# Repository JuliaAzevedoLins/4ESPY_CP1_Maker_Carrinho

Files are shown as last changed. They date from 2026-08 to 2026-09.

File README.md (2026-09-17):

# Carrinho Robótico WALL-E — 4ESPY | CP1

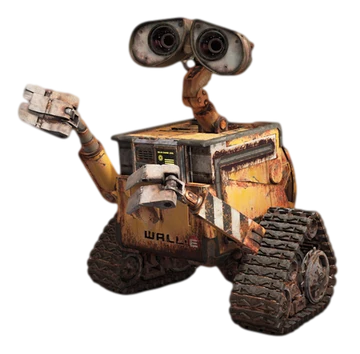
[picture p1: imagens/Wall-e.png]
WALL-E


Carrinho robótico físico e funcional, construído sobre um corpo impresso em 3D inspirado no personagem WALL-E (Pixar). O robô se movimenta por **duas rodas** acionadas por motores DC independentes, é pilotado à distância por um **controle PS5 DualSense** via Bluetooth e detecta obstáculos com um **sensor ultrassônico HC-SR04**, que bloqueia automaticamente o avanço diante de uma colisão iminente.

- **Turma:** 4ESPY
- **Avaliação:** CP1
- **Alunos:**
  - Julia Azevedo Lins — RM 98690
  - Luis Gustavo Barreto Garrido — RM 99210
  - Victor Hugo Aranda Forte — RM 99667
  - Felipe Cortez — RM 99750
  - Guilherme Akio — RM 98582

## Objetivo

Desenvolver um carrinho robótico funcional que integre projeto mecânico, fabricação digital, eletrônica e programação — capaz de se deslocar para frente e para trás, fazer curvas, receber comandos sem fio e reagir a obstáculos detectados por sensor.

## Principais funcionalidades

| Funcionalidade | Como funciona |
|---|---|
| **Locomoção diferencial** | Dois motores DC independentes acionam as rodas laterais. Frente, ré, curvas e giro sobre o próprio eixo |
| **Controle sem fio** | Controle PS5 DualSense por Bluetooth clássico (biblioteca Bluepad32). Stick esquerdo: avanço/ré. Stick direito: giro |
| **Velocidade proporcional** | PWM de 1 kHz com rampa de aceleração suave. Os gatilhos **R2/L2** ajustam a velocidade máxima em tempo real |
| **Freio de segurança** | O HC-SR04 bloqueia o avanço a menos de 20 cm de um obstáculo — mantendo ré e giro liberados, para o robô nunca ficar preso |
| **Calibração pelo celular** | O ESP32 serve uma página web com sliders que compensam a diferença de rotação entre os motores. Valores salvos na memória interna |
| **Atualização OTA** | Depois da primeira gravação por cabo, o firmware é atualizado pela rede Wi-Fi — sem abrir o corpo impresso |

## O carrinho finalizado

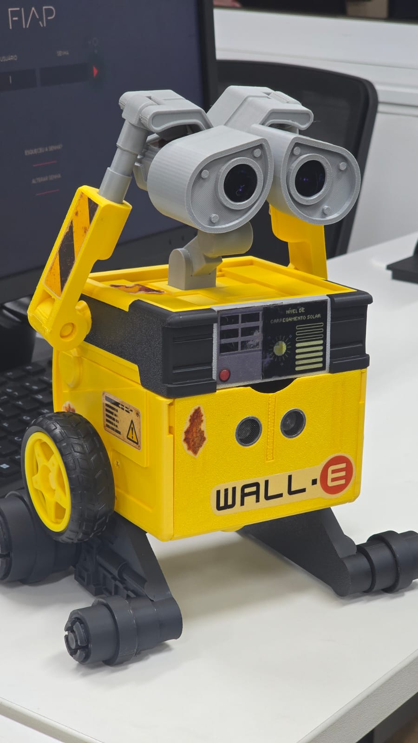
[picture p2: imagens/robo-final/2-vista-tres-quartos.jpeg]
Carrinho robótico WALL-E finalizado


| Vista frontal | Vista lateral | Eletrônica interna |
|---|---|---|
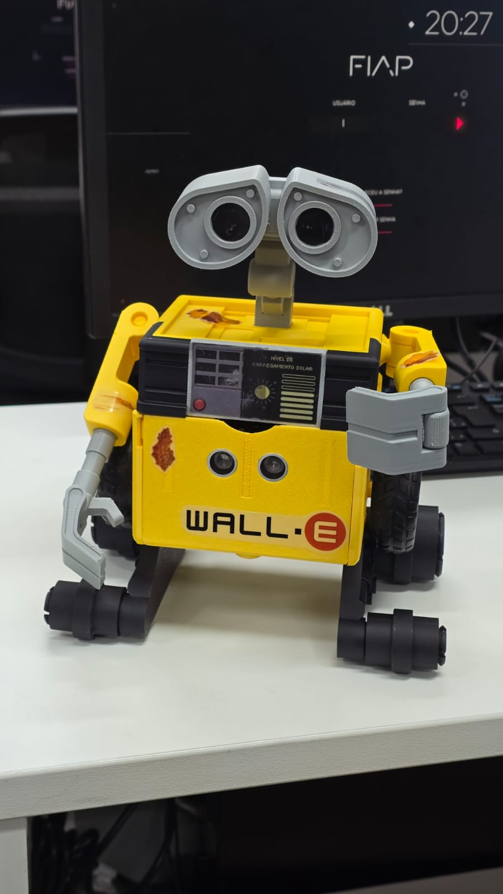
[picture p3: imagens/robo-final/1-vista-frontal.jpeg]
Vista frontal
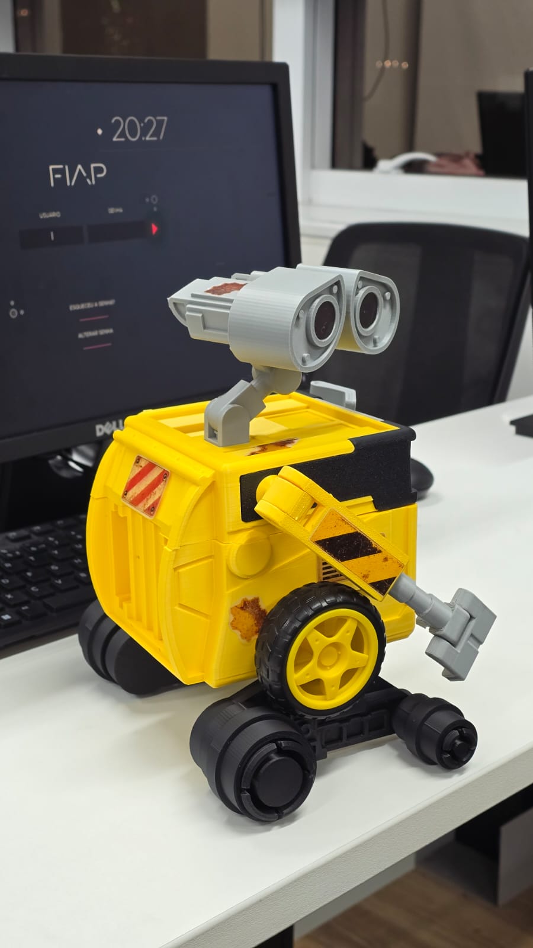
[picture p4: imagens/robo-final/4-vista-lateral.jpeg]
Vista lateral
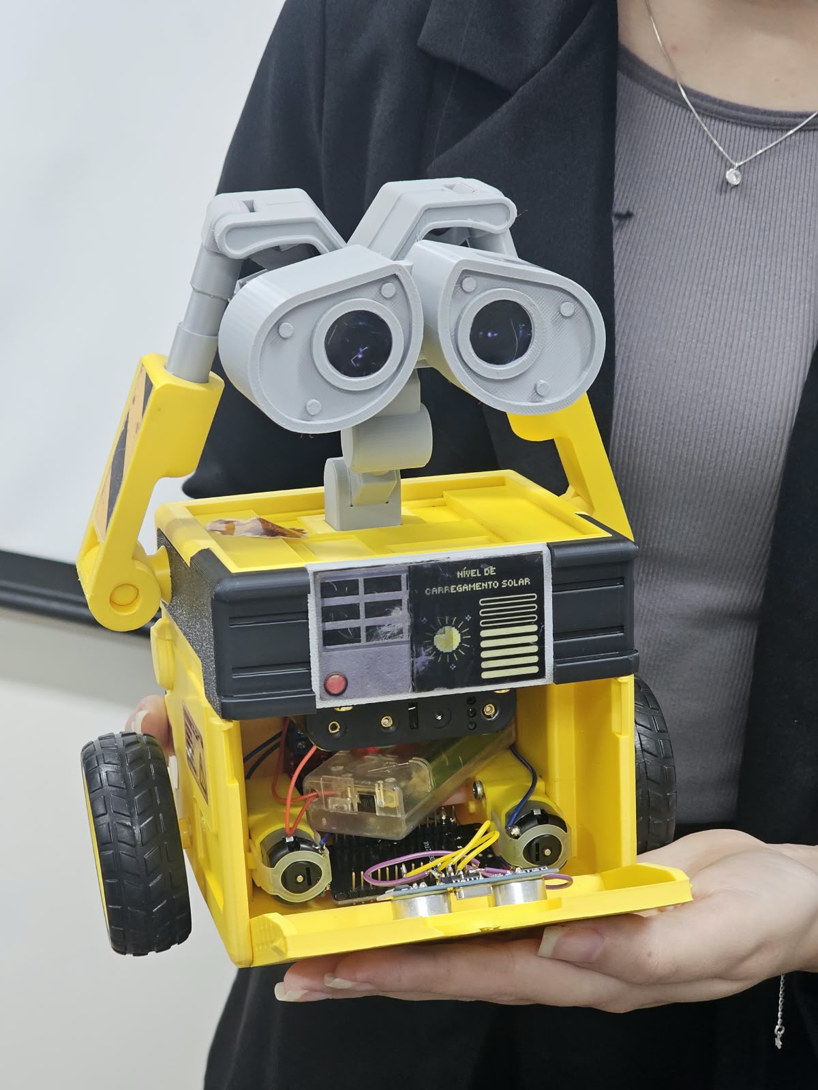
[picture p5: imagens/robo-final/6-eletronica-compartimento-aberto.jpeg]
Compartimento aberto
|  |  |  |

O sensor HC-SR04 fica embutido na face frontal e a tampa dianteira abre para baixo, dando acesso aos motores, à ponte H, ao ESP32 e às pilhas sem desmontar nada. O acabamento inclui pintura de desgaste, faixa preta no topo e adesivos ("WALL·E", painel de carregamento solar e etiquetas de advertência).

Mais fotos em [`imagens/robo-final/`](imagens/robo-final).

🎥 **Vídeos do funcionamento:** [1](<vídeo/funcionamento-1.mp4>) · [2](<vídeo/funcionamento-2.mp4>) · [3](<vídeo/funcionamento-3.mp4>) · [4](<vídeo/funcionamento-4.mp4>) — o robô em operação, comandado pelo controle PS5. A demonstração do sensor de aproximação está em [`vídeo/Motor + Sensor de Aproximação.mp4`](<vídeo/Motor + Sensor de Aproximação.mp4>).

## Especificações

| Item | Valor |
|---|---|
| Microcontrolador | ESP32 Dev Module (Bluetooth clássico) |
| Driver de motores | Ponte H dupla, 4 entradas em PWM |
| Motores | 2 × DC TT com caixa de redução |
| Tração | 2WD diferencial, 2 rodas laterais + apoio frontal impresso |
| Sensor | HC-SR04 frontal, detecção a 20 cm |
| Controle | PS5 DualSense (Bluepad32) |
| Alimentação | 6 × pilhas AA com chave liga/desliga |
| Estrutura | Corpo impresso em PLA — 204,4 × 126,0 × 77,7 mm |

## Como usar

1. Ligue a chave do suporte de pilhas.
2. Coloque o DualSense em pareamento: segure **PS + Create** até o LED piscar rápido.
3. Pilote: **stick esquerdo** anda e dá ré, **stick direito** gira, **R2/L2** ajustam a velocidade.
4. A menos de 20 cm de um obstáculo o avanço trava sozinho — use ré ou giro para sair.

Instruções completas (calibração, gravação do firmware e solução de problemas) na [seção 27 da documentação](Documentacao.md).

## Organização do repositório

```
├── README.md                     # este arquivo
├── Documentacao.md               # documentação técnica completa (28 seções)
│
├── Códigos/                      # firmware
│   ├── PS5_ESP32_Bluepad32.ino        # ⭐ firmware oficial do robô (ESP32)
│   ├── secrets.h.example              # modelo das credenciais de Wi-Fi
│   ├── README.md                      # setup, compilação e uso
│   └── testes-aula16/                 # códigos históricos dos testes de bancada
│
├── Modelo 3d/                    # projeto mecânico
│   ├── Wall-E_Articulated(3).3mf      # projeto do slicer (16 chapas)
│   ├── stl/                           # STL das peças modeladas pela equipe
│   ├── renders/                       # renders das 16 chapas de impressão
│   └── README.md                      # modelagem, adaptações e parâmetros
│
├── Organização/                  # planejamento e gestão
│   ├── MVP.html                       # produto mínimo viável e critérios de aceite
│   ├── MoSCoW.html                    # priorização Must/Should/Could/Won't
│   ├── Backlog.html                   # tarefas, responsáveis, prazos e critérios
│   ├── Dependências.html              # precedências e caminho crítico
│   ├── Kanban.html                    # situação das atividades
│   ├── Planilha-de-custos.xlsx        # custos (Excel)
│   ├── Resumo-Planilha-de-custos.html # resumo visual dos custos
│   └── README.md                      # índice dos entregáveis e equipe
│
├── croqui/                       # croqui da concepção inicial
├── imagens/                      # fotos do projeto
│   └── robo-final/                    # fotos do robô finalizado
└── vídeo/                        # vídeos dos testes e da demonstração final
```

## Documentação

A [documentação técnica completa](Documentacao.md) é **cumulativa** e registra todo o processo:

| Seções | Conteúdo |
|---|---|
| 1 – 19 | Concepção, requisitos, especificações, chassi, carenagem e croqui |
| 20 – 21 | Montagem e testes de bancada (Arduino Uno) — registro histórico |
| 22 | Planejamento e gestão |
| **23** | **Projeto mecânico e fabricação** — adaptações, peças próprias, impressão |
| **24** | **Hardware, eletrônica e firmware** — pinagem, alimentação, funcionamento do código |
| **25** | **Testes, problemas e correções** — 10 testes e 12 problemas resolvidos |
| **26** | **Evolução e decisões de projeto** |
| **27** | **Instruções de uso** |
| **28** | **Evidências finais** |

Os artefatos de planejamento (MVP, MoSCoW, backlog, dependências, kanban e custos) estão na pasta [`Organização/`](<Organização/README.md>).

## Status do projeto

- [x] Ficha de requisitos, requisitos funcionais e físicos, especificações e lista de componentes
- [x] Arquitetura do sistema e distribuição dos componentes
- [x] Croqui do chassi (concepção)
- [x] Diagrama de blocos e de alimentação, validados em bancada
- [x] Testes de bancada: motores, sensor de aproximação e controle sem fio
- [x] Modelagem 3D: adaptação do corpo, extensor de eixo, roda boba e travessa interna
- [x] Impressão 3D de todas as peças do corpo, dos braços, da cabeça e dos conjuntos laterais
- [x] Migração para ESP32 com controle PS5, calibração web e OTA
- [x] Integração final: mecânica + eletrônica + firmware
- [x] Acabamento: pintura de desgaste, faixa preta e adesivos
- [x] Fotos do robô finalizado e vídeos da demonstração

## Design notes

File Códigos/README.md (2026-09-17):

# Firmware — Carrinho Robótico WALL-E

Carrinho de tração diferencial controlado por um **controle PS5 DualSense** via Bluetooth, usando um **ESP32**.

| Arquivo | O que é |
|---|---|
| [`PS5_ESP32_Bluepad32.ino`](PS5_ESP32_Bluepad32.ino) | ⭐ **Firmware oficial** — o que roda no robô entregue |
| [`secrets.h.example`](secrets.h.example) | Modelo das credenciais de Wi-Fi (copiar para `secrets.h`) |
| [`testes-aula16/`](testes-aula16) | Códigos históricos dos testes de bancada em Arduino Uno |

## Recursos

- Conexão com o controle DualSense via [Bluepad32](https://github.com/ricardoquesada/bluepad32) (mais estável que as libs baseadas em spoof de MAC).
- Controle diferencial: stick esquerdo (frente/ré) + stick direito (giro).
- Rampa de aceleração suave e zona morta nos sticks.
- R2/L2 ajustam a velocidade máxima em tempo real.
- **Freio de segurança por sensor**: o HC-SR04 bloqueia o avanço a menos de 20 cm de um obstáculo, mantendo ré e giro liberados.
- **OTA**: depois da primeira gravação por cabo, novas versões do firmware podem ser enviadas pela rede Wi-Fi (`Tools > Port` no Arduino IDE mostra o carrinho como porta de rede).
- **Calibração pelo celular**: o ESP32 sobe uma página web simples (`http://<ip-do-esp32>/`) com sliders para compensar motores desbalanceados, salvos na memória interna (NVS).

## Hardware

- ESP32 Dev Module (precisa de Bluetooth clássico — não funciona em chips só-BLE como S2/S3/C3/C6)
- Driver de motor duplo (ponte H) — 4 pinos de controle: `IN1`, `IN2` (motor A), `IN3`, `IN4` (motor B)
- 2 motores DC TT com caixa de redução
- Sensor ultrassônico HC-SR04
- Controle PS5 DualSense
- 6 × pilhas AA

### Pinagem

| Sinal | GPIO | Canal LEDC |
|---|---|---|
| IN1 — motor A | 26 | 0 |
| IN2 — motor A | 27 | 1 |
| IN3 — motor B | 32 | 2 |
| IN4 — motor B | 33 | 3 |
| TRIG — HC-SR04 | 4 | — |
| ECHO — HC-SR04 | 18 | — |

> ⚠️ **Alimente o HC-SR04 em 3,3 V**, não em 5 V. Em 5 V o pino ECHO devolve 5 V e danifica o GPIO do ESP32, que tolera apenas 3,3 V. Em 3,3 V o sensor dispensa divisor resistivo.

> O motor B tem a polaridade invertida **em software** (`aplicaMotorB()`), porque os dois motores ficam montados espelhados no corpo. Trocar os fios do motor B na ponte H quebra esse pareamento.

## Configuração antes de compilar

1. Instale o pacote de placas do Bluepad32 (ver [instruções do projeto](https://github.com/ricardoquesada/bluepad32)).
2. No Arduino IDE, selecione a placa `ESP32 Bluepad32 Arduino / ESP32 + Bluepad32 Arduino > ESP32 Dev Module`.
3. Em `Tools > Partition Scheme`, escolha uma opção **com OTA** (não use nada com "No OTA" no nome).
4. Copie `secrets.h.example` para `secrets.h` e preencha com o nome e senha da sua rede wifi:
   ```cpp
   const char* WIFI_SSID = "sua-rede";
   const char* WIFI_PASS = "sua-senha";
   ```
   `secrets.h` está no `.gitignore` e nunca deve ser commitado.
5. Grave por cabo USB a primeira vez.

## Uso

- Ao ligar, o ESP32 conecta no wifi e imprime o IP no Serial Monitor (115200 baud).
- Coloque o DualSense em modo pareamento (segure PS + Create até o LED piscar rápido).
- Depois da primeira gravação, novas atualizações podem ser feitas por OTA (mesma rede wifi, sem cabo).
- Para calibrar os motores, acesse `http://<ip-do-esp32>/` pelo celular (mesma rede) e ajuste os sliders enquanto anda com o carrinho pra frente.

### Se o controle não conectar

Descomente `BP32.forgetBluetoothKeys();` no `setup()`, grave, ligue uma vez e comente de novo. Isso apaga pareamentos antigos guardados no ESP32.

## Explicação do funcionamento

O detalhamento da lógica do firmware — mistura diferencial, zona morta, rampa de aceleração, freio de segurança, calibração web e OTA — está na **seção 24** da [documentação técnica](../Documentacao.md).

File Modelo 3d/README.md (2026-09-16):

# Modelagem 3D e Fabricação — Carrinho Robótico WALL-E

Esta pasta reúne o projeto mecânico do robô: o arquivo de projeto do slicer, os STL das peças desenvolvidas pela equipe e os renders das chapas de impressão.

## Conteúdo

| Arquivo / pasta | O que é |
|---|---|
| `Wall-E_Articulated(3).3mf` | Projeto completo no Bambu Studio — 16 chapas, todas as peças posicionadas, cortes e perfis de impressão |
| `stl/` | STL das peças **desenvolvidas/adaptadas pela equipe** |
| `renders/` | Renders das 16 chapas de impressão, extraídos do próprio projeto |

## Modelo base

O corpo, a cabeça, os braços e os conjuntos laterais partem do modelo **"WALL-E Robot - Articulated"**, do designer **RoboDIYer** (MakerWorld, `DesignModelId US945b2b739cf63c`, Standard Digital File License). O modelo original é uma figura articulada decorativa, com esteiras funcionais em TPU, montagem por encaixe e sem qualquer previsão de eletrônica embarcada.

A equipe partiu dele e o converteu em um robô motorizado. As adaptações estão descritas abaixo.

## Adaptações feitas pela equipe

O modelo original é uma figura de brinquedo: as esteiras giram livres, empurradas com a mão. Transformá-lo em um carrinho motorizado exigiu quatro intervenções no projeto mecânico.

> **Tração na versão montada.** O conjunto de esteiras do modelo original não foi usado como elemento de tração. Na montagem final, cada motor aciona uma **roda de borracha** fixada ao seu eixo pelo extensor impresso, e os conjuntos laterais impressos (track frames com roletes) permanecem no robô como **apoio no piso e elemento visual** das esteiras do personagem. O projeto do slicer mantém as peças `Track x2` e o perfil de TPU do modelo original — elas não fazem parte do robô entregue.

| Peça | Dimensões | Por que existe |
|---|---|---|
| `corpo-wall-e-furado.stl` | 204,4 × 126,0 × 77,7 mm | Corpo do WALL-E perfurado por operação booleana. Os furos abrem passagem para os eixos dos motores DC, para a fiação e para o sensor HC-SR04 na face frontal. O modelo original é maciço nessas regiões. |
| `extensor-de-eixo.stl` (×2) | 7,6 × 24,0 × 6,4 mm | **Peça-chave do projeto.** Acopla o eixo do motor DC TT à roda motriz. O motor fica dentro do corpo e a roda, fora da lateral — o extensor vence essa distância e transmite o torque. Sem ele, não há como motorizar o modelo original. |
| `roda-boba-caster.stl` | 86,0 × 36,0 × 15,0 mm | Suporte de roda boba. Como a tração passou a ser motorizada e concentrada nas duas rodas laterais, o conjunto precisou de pontos de apoio adicionais para não cabecear. Atende ao requisito RFIS05. |
| `travessa-interna.stl` | 98,0 × 25,0 × 14,0 mm | Travessa interna que sustenta e alinha os motores dentro do corpo, mantendo os dois eixos coaxiais. |

### Corte do corpo para impressão

O corpo montado tem 204 × 126 × 78 mm e não cabia em uma única chapa com orientação adequada. Ele foi **seccionado dentro do Bambu Studio** em três partes (`Body_B_B`, `Body_B_B_A`, `Body_B_B_B_B`), reunidas por **7 pinos de encaixe** (`Conector-1` a `Conector-7`, duplicados nas duas interfaces de corte).

O corte trouxe um ganho que não estava previsto: o corpo passou a **abrir**, dando acesso à eletrônica interna (ESP32, ponte H e pilhas) sem desmontar rodas, braços ou cabeça. Isso atende diretamente ao requisito RFIS06 — a carenagem não pode impedir o acesso aos componentes para manutenção.

Uma primitiva cilíndrica (`Genérico-Cilindro`) foi usada como ferramenta de subtração booleana para abrir as passagens de eixo.

## Chassi e carenagem são a mesma peça

Na concepção inicial (seção 14 da [documentação técnica](../Documentacao.md)) o projeto previa duas peças distintas: um chassi plano de 220 × 140 × 35 mm e uma carenagem estética montada por cima.

Na versão final essa separação deixou de existir. **O corpo impresso do WALL-E é, ao mesmo tempo, a estrutura que sustenta os componentes e a carenagem estética.** Os motores, o ESP32, a ponte H e as pilhas ficam alojados dentro dele; as rodas motrizes saem pelas laterais, acopladas aos eixos dos motores, e os conjuntos laterais impressos apoiam o robô no piso.

A mudança eliminou uma peça, reduziu o peso e melhorou o resultado visual — o robô é o personagem, e não um chassi com uma casca por cima.

## Parâmetros de impressão

| Parâmetro | Valor |
|---|---|
| Impressora | Bambu Lab A1, bico 0,4 mm |
| Perfil | 0.20 mm Standard @BBL A1 |
| Altura de camada | 0,2 mm |
| Paredes | 2 |
| Preenchimento | 15% |
| Suporte | Árvore (automático) |
| Brim | Automático |
| Chapas | 16 |
| Filamentos | 5 × PLA (amarelo, preto, prata, vermelho, cinza) + 1 × TPU 95A (peças do modelo original, não utilizadas) |

Peças que devem ser impressas juntas, como conjunto *print-in-place* (não separar nas chapas): corpo + tampa frontal; braço + junta de ombro; antebraço + garra.

## Acabamento

Depois de impressas, as peças receberam um trabalho de acabamento que não vem do modelo original:

- **Pintura de desgaste (weathering)** simulando ferrugem e sujeira no corpo, nos braços e na cabeça, reproduzindo o aspecto envelhecido do personagem no filme;
- **Faixa preta texturizada** aplicada no topo e nas laterais superiores do corpo;
- **Adesivos impressos**: logotipo "WALL·E" na tampa frontal, painel "NÍVEL DE CARREGAMENTO SOLAR" na face superior, etiqueta de advertência na lateral e faixas de perigo no braço;
- **Impressão multicolor** separando corpo (amarelo), cabeça e braços (cinza), conjuntos laterais e painel (preto) e detalhes (vermelho).

As fotos do resultado estão em [`imagens/robo-final/`](../imagens/robo-final).

## Versões do modelo

| Versão | Registro |
|---|---|
| v1 | Modelo base importado do MakerWorld, sem alterações |
| v2 | `Wall-E_Articulated(2).3mf` — corte do corpo e primeiros furos |
| v3 | `Wall-E_Articulated(3).3mf` — **versão atual**: furação final, extensor de eixo, roda boba, travessa interna e reorganização das 16 chapas |

O encadeamento das versões está registrado dentro do próprio projeto: cada peça do arquivo atual carrega o metadado `source_file` apontando para `Wall-E_Articulated(2).3mf`.

## Renders das chapas

Os 16 renders em `renders/` mostram o arranjo de cada chapa de impressão exatamente como foi enviado à impressora.

| | | | |
|---|---|---|---|
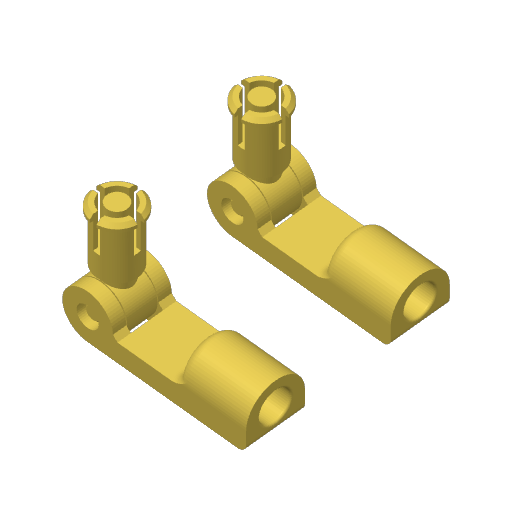
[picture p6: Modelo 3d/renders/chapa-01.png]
Chapa 1
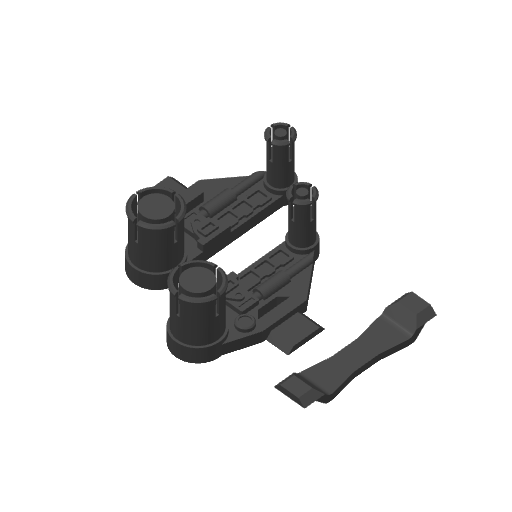
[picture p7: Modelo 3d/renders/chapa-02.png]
Chapa 2
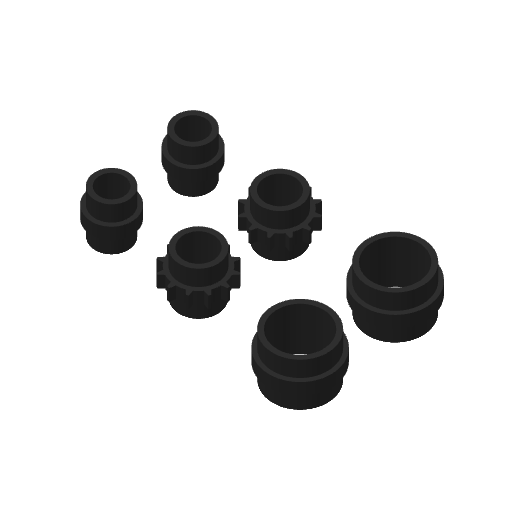
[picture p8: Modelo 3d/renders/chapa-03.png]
Chapa 3
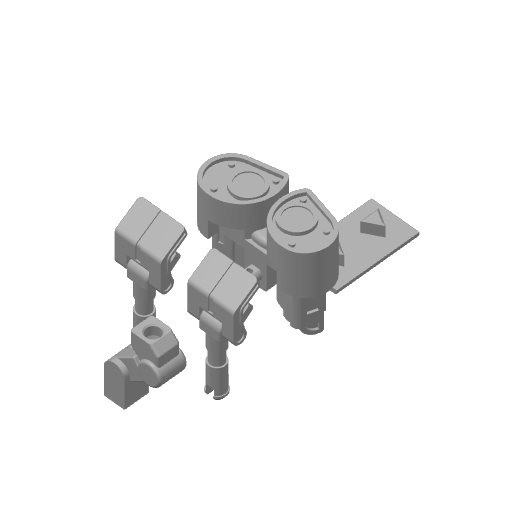
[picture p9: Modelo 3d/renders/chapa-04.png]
Chapa 4
|  |  |  |  |
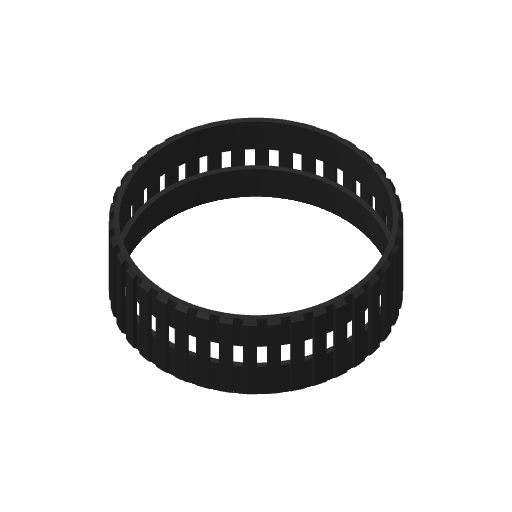
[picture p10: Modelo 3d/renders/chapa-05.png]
Chapa 5
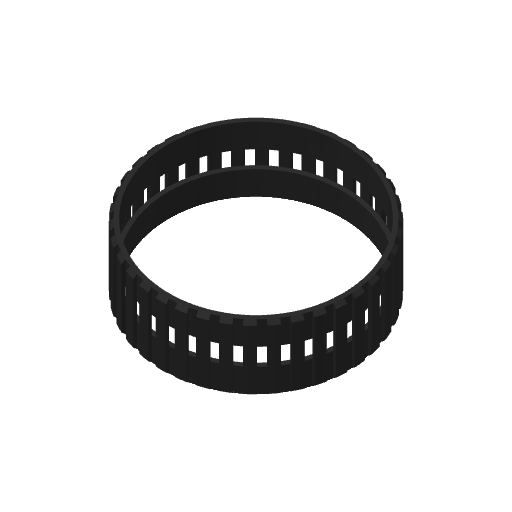
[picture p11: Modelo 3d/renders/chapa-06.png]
Chapa 6
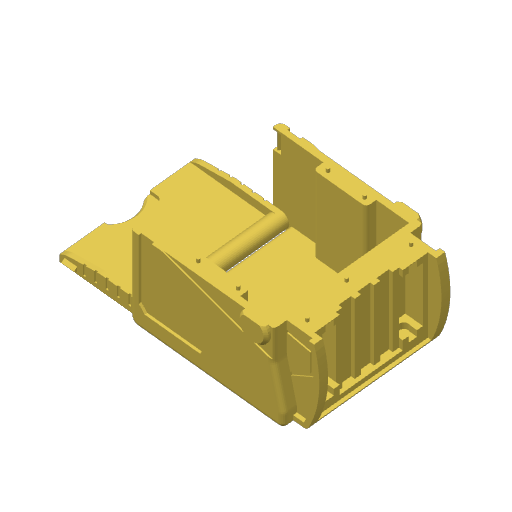
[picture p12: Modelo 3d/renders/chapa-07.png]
Chapa 7
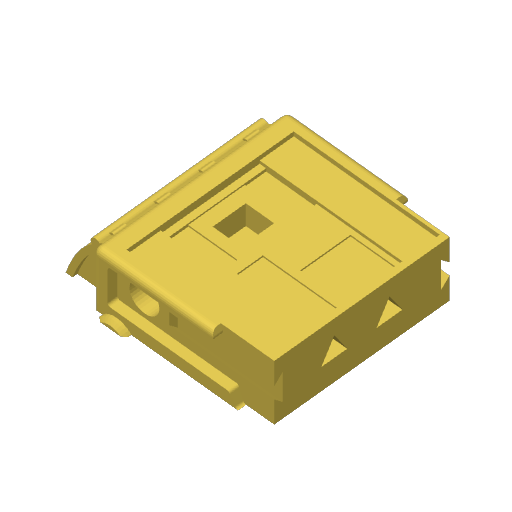
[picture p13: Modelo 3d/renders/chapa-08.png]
Chapa 8
|  |  |  |  |
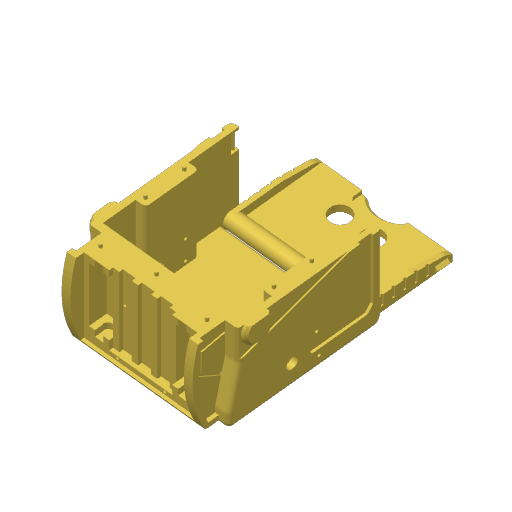
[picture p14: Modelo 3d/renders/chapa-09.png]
Chapa 9
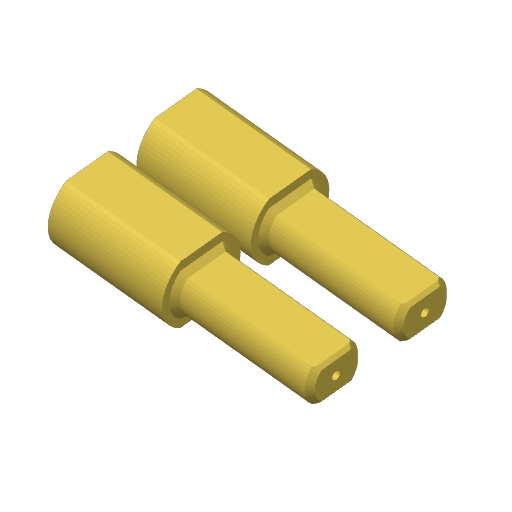
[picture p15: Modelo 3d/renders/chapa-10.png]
Chapa 10
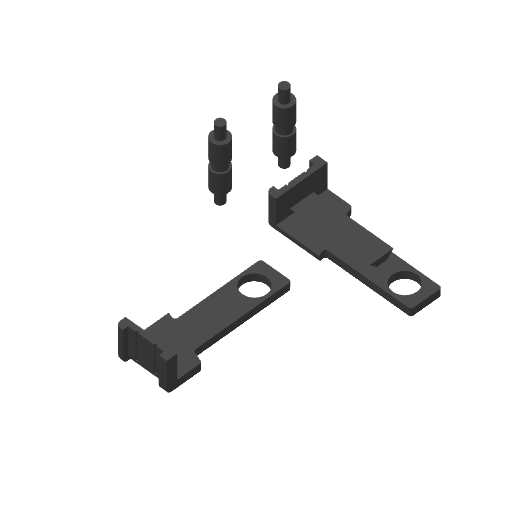
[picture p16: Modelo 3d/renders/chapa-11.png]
Chapa 11
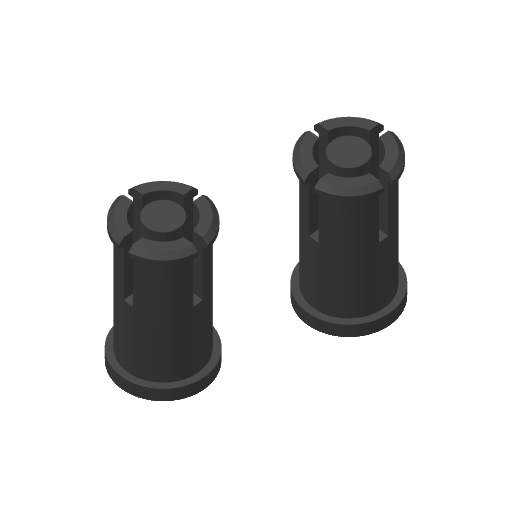
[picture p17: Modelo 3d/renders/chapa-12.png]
Chapa 12
|  |  |  |  |
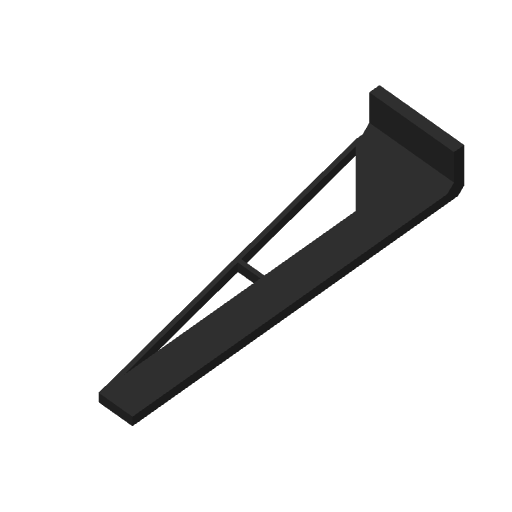
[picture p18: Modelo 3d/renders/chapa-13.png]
Chapa 13
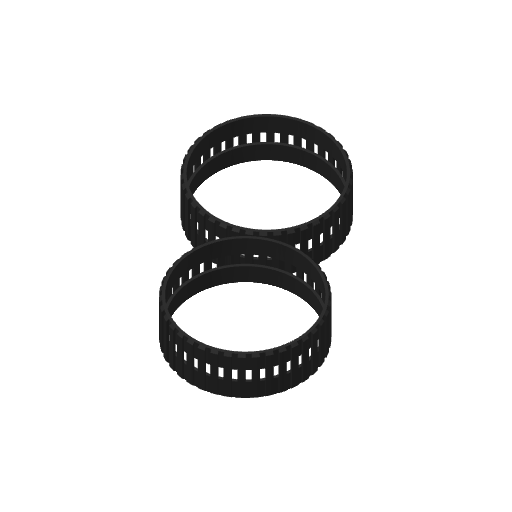
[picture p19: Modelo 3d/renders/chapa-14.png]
Chapa 14
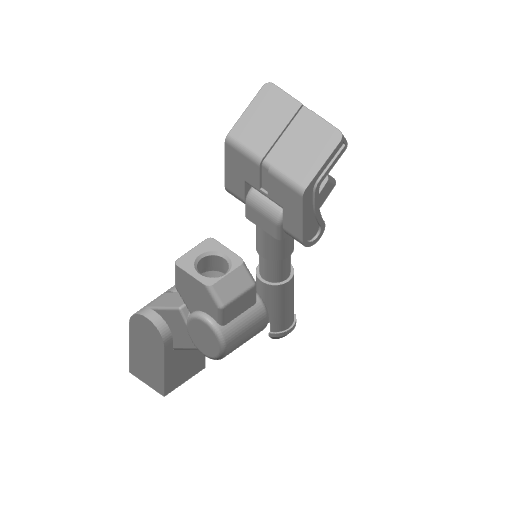
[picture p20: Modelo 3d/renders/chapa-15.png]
Chapa 15
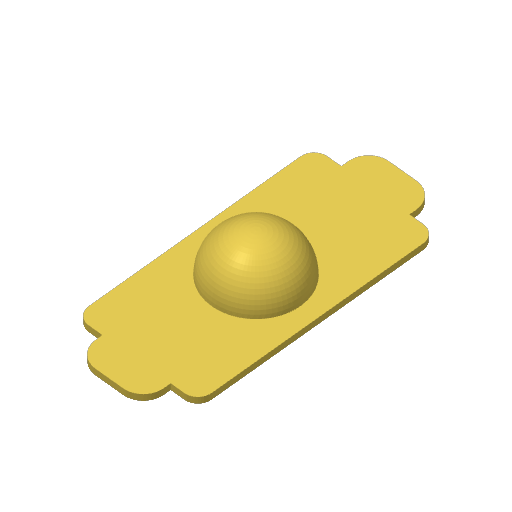
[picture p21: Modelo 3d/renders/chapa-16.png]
Chapa 16
|  |  |  |  |

## Como reproduzir

1. Abra `Wall-E_Articulated(3).3mf` no Bambu Studio (2.07 ou superior).
2. Confirme o perfil `0.20mm Standard @BBL A1` e a impressora Bambu Lab A1 com bico 0,4 mm.
3. Fatie e imprima chapa por chapa. As chapas das peças `Track x2`, em TPU, podem ser puladas: elas não fazem parte do robô entregue.
4. Aplique o acabamento descrito acima.
5. Para reimprimir apenas as peças da equipe, use os STL em `stl/` — eles já saem nas dimensões finais, em milímetros.

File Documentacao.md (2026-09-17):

# Carrinho Robótico WALL-E

WALL-E

## Identificação Acadêmica

- **Turma:** 4ESPY
- **Avaliação:** CP1
- **Alunos:**
  - Julia Azevedo Lins — RM 98690
  - Luis Gustavo Barreto Garrido — RM 99210
  - Victor Hugo Aranda Forte — RM 99667
  - Felipe Cortez — RM 99750
  - Guilherme Akio — RM 98582

---

## 1. Título do Projeto

**Carrinho Robótico WALL-E** — Projeto de carrinho robótico físico e funcional, com carenagem estética inspirada no personagem WALL-E (filme *WALL-E*, Pixar).

---

## 2. Descrição do Projeto

O projeto **Carrinho Robótico WALL-E** consiste em um carrinho robótico físico e funcional, desenvolvido na disciplina de Project-based Maker Lab. O robô é construído sobre um corpo impresso em 3D inspirado no personagem WALL-E (Pixar), movimenta-se por meio de duas rodas acionadas por motores DC independentes, é comandado à distância por um controle **PS5 DualSense** via Bluetooth e detecta obstáculos com um sensor ultrassônico **HC-SR04**, que bloqueia automaticamente o avanço diante de uma colisão iminente.

O projeto atravessou três etapas: concepção e ficha de requisitos (seções 1 a 19), montagem e testes de bancada (seções 20 e 21) e integração da versão final entregue (seções 23 a 28).

---

### Como ler este documento

Este documento é **cumulativo**: ele preserva o registro de cada etapa, inclusive das decisões que foram depois revistas, porque a evolução do projeto faz parte da entrega.

| Seções | O que contêm | Status |
|---|---|---|
| 1 a 19 | Concepção inicial, ficha de requisitos, croqui | Atualizadas para a versão final; onde a concepção foi superada, o texto indica o que mudou e por quê |
| 20 e 21 | Montagem de bancada e testes com Arduino Uno | **Registro histórico** — não descrevem o robô entregue |
| 23 a 28 | Versão final: modelagem 3D, eletrônica, firmware, testes, uso e evidências | **Descrevem o robô entregue** |

Em caso de divergência, **valem as seções 23 a 28**.

---

## 3. Objetivo

Desenvolver um carrinho robótico funcional, inspirado visualmente no personagem WALL-E, capaz de:

- Movimentar-se por meio do acionamento dos motores, permitindo deslocamento para frente, para trás e curvas;
- Receber comandos de um controle remoto sem fio;
- Detectar obstáculos por meio de um sensor de distância;
- Apresentar uma carenagem externa que remeta às características visuais do personagem que inspira o projeto.

---

## 4. Escopo

O escopo do projeto compreende o robô completo, entregue e funcional:

- Ficha de requisitos, requisitos funcionais e físicos;
- Projeto mecânico: adaptação, modelagem e impressão 3D do corpo, das peças de acoplamento e da roda boba;
- Montagem elétrica: microcontrolador, ponte H, motores, sensor e alimentação por pilhas;
- Firmware do ESP32: controle diferencial dos motores, comunicação sem fio com o controle PS5 e leitura do sensor de distância;
- Testes funcionais de locomoção, comunicação remota e detecção de obstáculos;
- Documentação de todo o processo neste repositório.

Não fazem parte do escopo: navegação autônoma (o robô só se move sob comando do controle), mapeamento de ambiente e uso de bateria recarregável.

---

## 5. Ficha de Requisitos

A tabela abaixo apresenta a **ficha final**, com o que foi planejado e o que efetivamente ficou no robô entregue.

| Item | Planejado (concepção) | **Final (entregue)** |
|---|---|---|
| Dimensões do corpo | 220 × 140 mm, altura 35 mm | **204,4 × 126,0 × 77,7 mm** |
| Quantidade de motores | 2 motores DC com caixa de redução | 2 motores DC TT com caixa de redução ✔ |
| Configuração de tração | 2WD (tração diferencial) | 2WD diferencial ✔ |
| Placa controladora | ESP32 | ESP32 Dev Module ✔ |
| Driver de motores | TB6612FNG | **Ponte H dupla L298N** (ver nota) |
| Sensor de distância | HC-SR04 | HC-SR04, frontal ✔ |
| Elemento de tração | 2 rodas motrizes | 2 rodas motrizes de borracha, acopladas por extensor de eixo ✔ |
| Roda de apoio | 1 roda caster | Roda boba traseira modelada pela equipe ✔ |
| Alimentação | Pilhas não recarregáveis, posição central/inferior | 6 × pilhas AA em suporte com chave liga/desliga |
| Controle remoto | Sem fio, via recursos do ESP32 | **Controle PS5 DualSense**, Bluetooth clássico via Bluepad32 |
| Material do chassi | Impressão 3D | Impressão 3D em PLA ✔ |
| Material da carenagem | A definir | **Não há peça separada** — o corpo impresso é chassi e carenagem |

> **Nota sobre a ponte H.** O firmware oficial aciona os motores por **quatro entradas de controle com PWM direto** (`IN1`–`IN4`), sem pinos de *enable* ou *standby* separados. Essa é a ligação típica de um **L298N** com os jumpers ENA/ENB fechados — módulo já validado na montagem de bancada (seção 20) e presente na planilha de custos. Um TB6612FNG exigiria a topologia `PWMA`/`AIN1`/`AIN2`/`STBY`, que **não** corresponde ao código entregue. Caso a equipe tenha substituído o módulo na montagem final, basta atualizar esta linha e a tabela de pinagem da seção 24.2 — a lógica do firmware não muda.

---

## 6. Requisitos Funcionais

| Código | Descrição |
|---|---|
| RF01 | O robô deve movimentar-se para frente. |
| RF02 | O robô deve movimentar-se para trás. |
| RF03 | O robô deve realizar curvas para a esquerda e para a direita utilizando controle diferencial dos motores. |
| RF04 | O robô deve receber comandos de um controle remoto sem fio. |
| RF05 | O robô deve detectar obstáculos utilizando um sensor de distância. |
| RF06 | O sistema deve ser capaz de interromper ou modificar o movimento quando um obstáculo for detectado a uma distância previamente definida. |

---

## 7. Requisitos Físicos

| Código | Descrição |
|---|---|
| RFIS01 | O chassi deve possuir aproximadamente 220 × 140 mm. |
| RFIS02 | O chassi deve ser produzido por impressão 3D. |
| RFIS03 | O chassi deve possuir espaço para acomodar os componentes eletrônicos. |
| RFIS04 | O chassi deve permitir a fixação dos dois motores. |
| RFIS05 | O chassi deve permitir a instalação das duas rodas motrizes e da roda caster. |
| RFIS06 | A carenagem deve ser fixada sobre o chassi sem impedir o acesso aos componentes para manutenção. |

---

## 8. Especificações Técnicas

### 8.1 Parâmetros definidos

- **Placa controladora:** ESP32 Dev Module — processa os comandos, aciona os motores, mantém a comunicação sem fio e lê o sensor de distância. Exige chip com **Bluetooth clássico**; variantes somente-BLE (S2, S3, C3, C6) não funcionam com a biblioteca utilizada;
- **Driver de motores:** ponte H dupla com quatro entradas de controle (L298N), acionada por PWM direto nas quatro entradas;
- **Sensor de distância:** HC-SR04, montado na face frontal do corpo;
- **Configuração de tração:** 2WD diferencial — cada roda lateral é acionada por um motor independente;
- **Comunicação:** Bluetooth clássico com controle PS5 DualSense, via biblioteca **Bluepad32**;
- **Rede Wi-Fi (auxiliar):** o ESP32 também se conecta a uma rede Wi-Fi para permitir atualização de firmware por **OTA** e uma **página web de calibração** dos motores.

### 8.2 Parâmetros definidos durante a execução

Os parâmetros abaixo estavam pendentes na concepção e foram **fechados durante a implementação**. Os valores são os que estão efetivamente no firmware entregue (`Códigos/PS5_ESP32_Bluepad32.ino`).

| Parâmetro | Valor final | Onde foi definido |
|---|---|---|
| Alimentação | 6 × pilhas AA alcalinas (9 V nominais), suporte com chave liga/desliga | Montagem final |
| Modelo dos motores | Motor DC TT 3–6 V com caixa de redução, eixo duplo | Planilha de custos |
| Elemento de tração | 2 rodas de borracha acopladas ao eixo do motor pelo extensor impresso | Montagem final |
| Roda de apoio | Roda boba de 86 × 36 × 15 mm, modelada pela equipe | Modelagem 3D |
| Controle remoto | PS5 DualSense, Bluetooth clássico | Firmware |
| Distância de detecção | **20 cm** (`DISTANCIA_MIN_CM`) | Firmware |
| Alcance útil do sensor | ~2,5 m (timeout de 15 ms no `pulseIn`) | Firmware |
| Frequência de leitura do sensor | 1 leitura a cada 60 ms | Firmware |
| Velocidade máxima | PWM 200/255 no arranque, ajustável de 80 a 255 pelos gatilhos R2/L2 | Firmware |
| Frequência do PWM | 1 kHz, resolução de 8 bits | Firmware |
| Zona morta dos analógicos | 80 unidades (~15% do curso do stick) | Firmware |
| Rampa de aceleração | Incremento de 12 unidades a cada 15 ms | Firmware |
| Peso e autonomia | Não medidos — ver seção 25.4 | — |

---

## 9. Lista de Componentes

| Componente | Qtd. | Função | Origem |
|---|---|---|---|
| Corpo do WALL-E impresso em 3D | 1 | Estrutura e carenagem, em peça única | Impresso (PLA) |
| Roda motriz de borracha | 2 | Elemento de tração, acoplada ao eixo do motor | Comercial |
| Conjunto lateral (track frame + roletes) | 2 | Apoio do robô no piso e elemento visual das esteiras | Impresso |
| **Extensor de eixo** | 2 | Acopla o eixo do motor à roda dentada | **Modelado pela equipe** |
| **Roda boba (caster)** | 1 | Terceiro ponto de apoio, traseiro | **Modelada pela equipe** |
| **Travessa interna** | 1 | Alinha e sustenta os motores dentro do corpo | **Modelada pela equipe** |
| Motor DC TT com caixa de redução | 2 | Tração das rodas | Comercial |
| Placa controladora ESP32 Dev Module | 1 | Processamento, controle e comunicação sem fio | Comercial |
| Ponte H dupla (L298N) | 1 | Acionamento dos dois motores DC | Comercial |
| Sensor ultrassônico HC-SR04 | 1 | Detecção de obstáculos | Comercial |
| Suporte de pilhas 6 × AA com chave | 1 | Alimentação do sistema | Comercial |
| Pilhas AA alcalinas | 6 | Fonte de energia | Comercial |
| Controle PS5 DualSense | 1 | Envio de comandos ao robô | Comercial |
| Jumpers e cabos | — | Ligações entre os módulos | Comercial |

Peças impressas, dimensões e parâmetros de impressão estão detalhados em [`Modelo 3d/README.md`](<Modelo 3d/README.md>). Preços, links e status de compra estão na [planilha de custos](<Organização/Resumo-Planilha-de-custos.html>).

---

## 10. Arquitetura Geral do Sistema

```mermaid
flowchart TD
    PS5[Controle PS5 DualSense] -- Bluetooth classico / Bluepad32 --> ESP32[ESP32 Dev Module]
    HCSR04[Sensor HC-SR04] -- TRIG/ECHO --> ESP32
    CEL[Celular ou PC no mesmo Wi-Fi] -- HTTP: calibracao e OTA --> ESP32
    ESP32 -- IN1 IN2 IN3 IN4 em PWM --> PONTEH[Ponte H dupla L298N]
    PONTEH -- acionamento --> MOTORE[Motor Esquerdo]
    PONTEH -- acionamento --> MOTORD[Motor Direito]
    MOTORE --> RODAE[Roda Esquerda]
    MOTORD --> RODAD[Roda Direita]
    BAT[6x Pilhas AA] -- alimentacao --> PONTEH
    BAT -- alimentacao --> ESP32
```

O ESP32 é a unidade central: recebe os comandos do controle DualSense por Bluetooth clássico, lê continuamente o sensor de distância e converte as duas informações em sinais PWM para a ponte H, que aciona cada motor de forma independente.

Em paralelo, e sem interferir na pilotagem, o ESP32 mantém uma conexão Wi-Fi que serve a dois propósitos de apoio: **atualização de firmware por OTA** (sem cabo) e uma **página web de calibração** dos motores. Se a rede Wi-Fi não estiver disponível, o robô continua funcionando normalmente pelo controle — apenas esses dois recursos auxiliares ficam indisponíveis.

---

## 11. Distribuição dos Componentes no Chassi

> 📌 **Registro da concepção.** O esquema abaixo foi elaborado quando o projeto previa um chassi plano de 220 × 140 mm. Com a adoção do corpo do WALL-E como estrutura, a distribuição real dos componentes mudou — ela está descrita na **seção 23.4**. O esquema é mantido como registro da etapa de concepção.

A distribuição prevista dos componentes seguia a organização esquemática abaixo (vista superior):

```
                          FRENTE
                            ↓
        ┌──────────────────────────────────────┐
        │              HC-SR04                 │
        │           (sensor frontal)           │
        │                                      │
        │                ESP32                 │
        │        (placa controladora)          │
        │                                      │
        │                PILHAS                │
        │      (região central/inferior)       │
        │                                      │
        │              TB6612FNG               │
        │        (driver dos motores)          │
        │                                      │
        │     MOTOR                    MOTOR   │
        │   ESQUERDO                  DIREITO  │
        └──────────────────────────────────────┘
                           TRÁS
```

### 11.1 Justificativa do posicionamento

- **HC-SR04**: posicionado na parte frontal do chassi, permitindo a detecção de obstáculos no sentido de deslocamento principal;
- **ESP32**: posicionado em região central-superior, próxima ao sensor e equidistante dos dois motores, facilitando o roteamento de cabos;
- **Pilhas**: posicionadas na região central e baixa do chassi, contribuindo para o equilíbrio e a distribuição de peso;
- **TB6612FNG**: posicionado próximo à região dos motores, reduzindo o comprimento dos cabos de acionamento;
- **Motores**: posicionados nas laterais traseiras do chassi, um à esquerda e outro à direita, acionando diretamente as rodas motrizes.

---

## 12. Dimensões Previstas

> 📌 **Registro da concepção.** Tabela levantada em aula com dimensões típicas de mercado, quando os modelos ainda não estavam definidos. As dimensões reais das peças impressas estão na **seção 23.2**.

Tabela de referência com as dimensões típicas dos componentes previstos, utilizada como base para a atividade em aula de acordo com valores da Internet.

| Componente | Comprimento | Largura | Altura | Forma de Fixação |
|---|---|---|---|---|
| Motor esquerdo | ~65 mm (corpo + eixo) | ~24 mm (diâmetro do corpo) | ~18 mm | Parafusado no chassi via suportes laterais (bracket em L), na lateral traseira esquerda |
| Motor direito | ~65 mm (corpo + eixo) | ~24 mm (diâmetro do corpo) | ~18 mm | Parafusado no chassi via suportes laterais (bracket em L), na lateral traseira direita |
| ESP32 (DevKit V1) | ~55 mm | ~28 mm | ~13 mm | Encaixe em soquetes/pinos ou fixação com parafusos M3 + espaçadores (standoffs), posição central-superior |
| Ponte H (TB6612FNG) | ~20 mm | ~22 mm | ~5 mm | Fixação com parafusos M2/M3 + espaçadores, próxima aos motores |

**Observação:** os valores acima eram medidas de referência de mercado, levantadas quando o modelo exato de cada componente ainda não estava definido. Os parâmetros foram fechados durante a execução (seção 8.2) e as dimensões reais das peças impressas estão na seção 23.2.

---

## 13. Descrição do Funcionamento

O funcionamento do carrinho robótico segue a lógica operacional abaixo, implementada no firmware entregue:

1. O usuário comanda o robô pelo **controle PS5 DualSense**: o stick esquerdo (eixo Y) define avanço e ré; o stick direito (eixo X) define o giro;
2. O ESP32 recebe esses comandos por Bluetooth clássico, através da biblioteca Bluepad32;
3. Em paralelo, o ESP32 lê o **HC-SR04** a cada 60 ms, obtendo a distância até o obstáculo mais próximo à frente;
4. Os valores dos sticks passam por uma **zona morta** de ~15%, que descarta o ruído de repouso do analógico, e são convertidos em dois valores de potência por **mistura diferencial**: `motor A = avanço + giro` e `motor B = avanço − giro`;
5. Antes de chegar aos motores, esses valores passam por uma **rampa de aceleração** (12 unidades a cada 15 ms), que suaviza o arranque e evita que o robô empine ou derrape a roda;
6. O resultado é aplicado como **PWM** nas quatro entradas da ponte H, que aciona os dois motores de forma independente — permitindo frente, ré, curvas e giro sobre o próprio eixo;
7. **Freio de segurança (RF05 e RF06):** se o sensor acusar obstáculo a menos de **20 cm**, o firmware zera apenas o componente de avanço. A ré e o giro continuam liberados, de modo que o robô nunca fica preso contra um obstáculo — o usuário consegue sempre manobrar para sair.

O robô **não possui navegação autônoma**: todo movimento parte de um comando do controle. O sensor atua exclusivamente como trava de proteção sobre esse comando.

---

## 14. Descrição do Chassi

### 14.1 Concepção inicial

O projeto previa inicialmente um **chassi plano** de 220 × 140 × 35 mm, impresso em 3D, sobre o qual seria montada uma carenagem estética separada, inspirada no WALL-E.

### 14.2 Solução adotada

Durante a modelagem, a equipe concluiu que o corpo do WALL-E — retangular, oco e com os conjuntos laterais — **já era, em si, um chassi**. Manter uma placa plana embaixo dele significaria duplicar estrutura, aumentar peso e elevar o centro de gravidade sem ganho nenhum.

A decisão foi **eliminar o chassi plano** e usar o corpo impresso como estrutura portante. Características da solução final:

- Corpo impresso em 3D (PLA), conforme RFIS02 — **204,4 × 126,0 × 77,7 mm**;
- Interior oco, alojando ESP32, ponte H, suporte de pilhas e fiação (RFIS03);
- **Furação** feita pela equipe por operação booleana, abrindo passagem para os eixos dos motores, para os cabos e para a face do sensor (RFIS04);
- **Travessa interna** modelada pela equipe, que alinha e sustenta os dois motores mantendo os eixos coaxiais;
- Conjuntos laterais impressos (track frames com roletes) apoiando o robô no piso (RFIS05);
- **Roda boba traseira** modelada pela equipe, que fornece o terceiro ponto de apoio (RFIS05);
- Corpo **seccionado em três partes** unidas por 7 pinos de encaixe, o que permite abri-lo para acessar a eletrônica sem desmontar rodas, braços ou cabeça (RFIS06).

O detalhamento completo da modelagem, das adaptações e dos parâmetros de impressão está em [`Modelo 3d/README.md`](<Modelo 3d/README.md>) e resumido na seção 23.

---

## 15. Descrição da Carenagem

A carenagem é o elemento **estético** do projeto, responsável por reproduzir visualmente as características do personagem WALL-E.

### 15.1 Solução adotada: carenagem e chassi em peça única

A concepção inicial previa uma carenagem separada, montada sobre o chassi plano, com material a definir entre papel, papel cartão, papelão, MDF, acrílico, plástico ou impressão 3D.

Com a mudança descrita na seção 14.2, **essa separação deixou de existir**. O corpo impresso do WALL-E exerce as duas funções ao mesmo tempo: é a estrutura que sustenta motores e eletrônica e é, simultaneamente, o revestimento estético do robô.

Consequências da decisão:

| Critério | Resultado |
|---|---|
| Adequação ao chassi | Perfeita por construção — carenagem e chassi são a mesma peça, não há folga nem desalinhamento |
| Fixação | Não há: nada precisa ser fixado por cima, eliminando parafusos, fitas e colas aparentes |
| Acabamento | Impressão em PLA a 0,2 mm, com cores separadas por filamento (amarelo, preto, prata, vermelho e cinza) — sem pintura manual |
| Acesso aos componentes | Garantido pelo corte em três seções unidas por pinos de encaixe: o corpo abre para manutenção (RFIS06) |
| Criatividade | O robô **é** o personagem, em vez de um chassi genérico com uma casca por cima |

O material definitivo é, portanto, **PLA impresso em 3D**, com acabamento de pintura e adesivos descrito na seção 23.7.

### 15.2 Características visuais reproduzidas

- Corpo de formato retangular;
- Cabeça posicionada na parte superior do corpo;
- Dois olhos característicos do personagem;
- Braços laterais;
- Aparência geral de robô compacto;
- Elementos visuais que remetam às esteiras laterais do personagem.

Todos esses elementos estão presentes no robô montado, incluindo os braços articulados com garra, a cabeça com os dois olhos característicos e os conjuntos laterais que reproduzem as esteiras do personagem. Ver as fotos da seção 28.

---

## 16. Croqui do Chassi (concepção)

> 📌 **Registro da concepção.** As vistas abaixo foram desenhadas na etapa de concepção, quando o projeto previa um chassi plano de 220 × 140 × 35 mm com duas rodas motrizes. A geometria final do robô é outra — corpo do WALL-E de 204 × 126 × 78 mm com rodas laterais — e está documentada nos renders da **seção 23.3** e em [`Modelo 3d/renders/`](<Modelo 3d/renders/>). O croqui é mantido como registro da evolução do projeto.

### 16.0 Imagens do Croqui

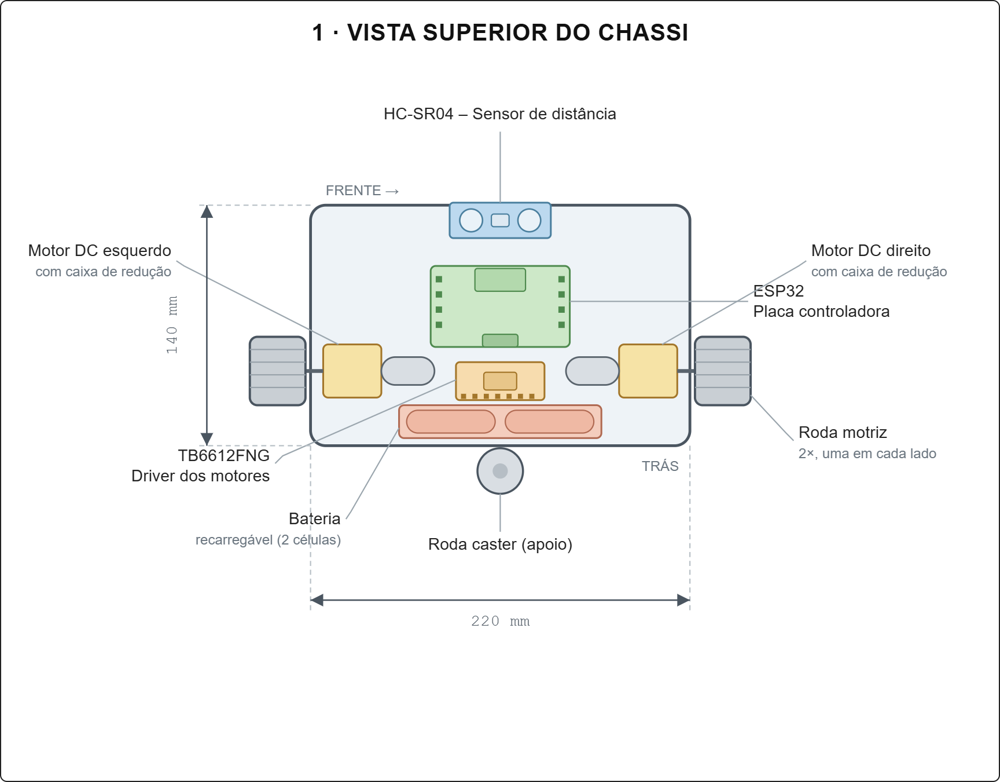
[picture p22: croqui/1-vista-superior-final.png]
Vista superior do chassi


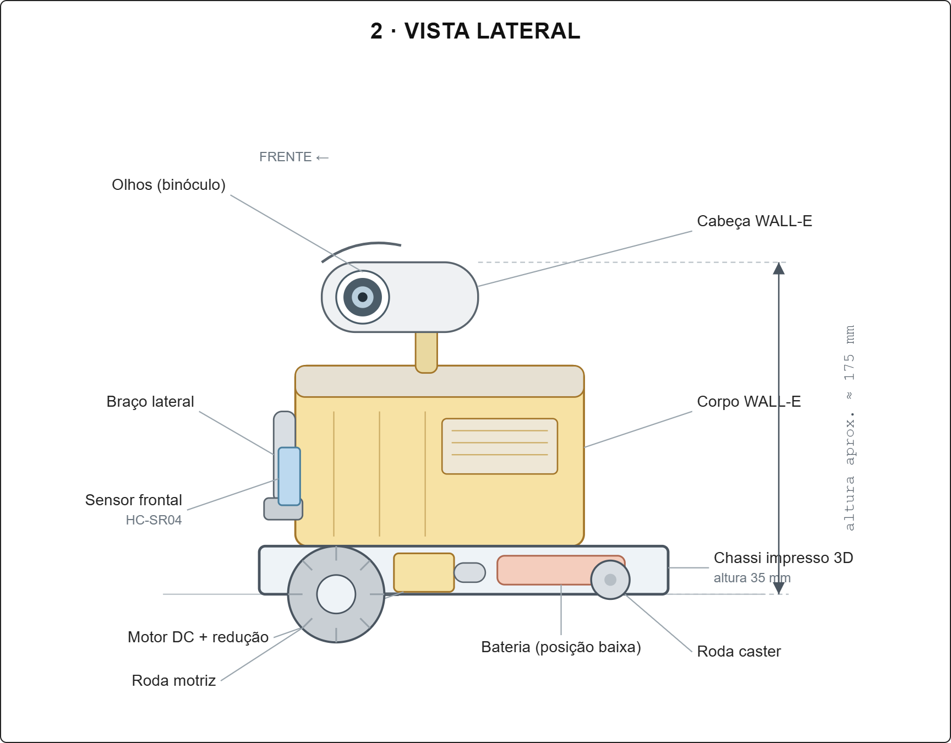
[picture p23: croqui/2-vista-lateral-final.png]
Vista lateral do robô


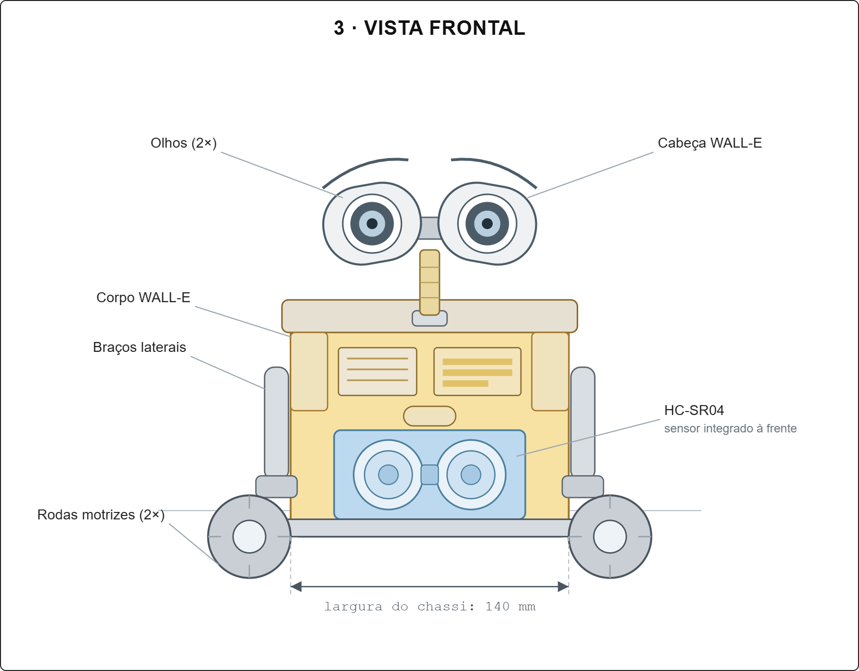
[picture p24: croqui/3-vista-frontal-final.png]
Vista frontal do robô


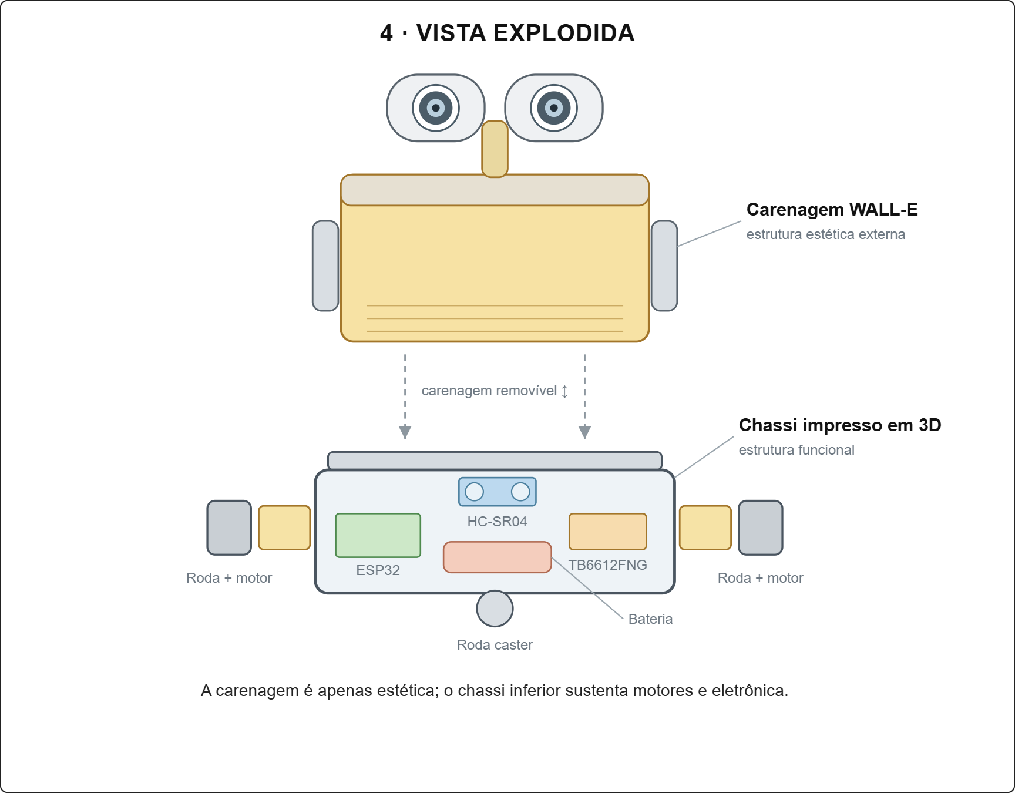
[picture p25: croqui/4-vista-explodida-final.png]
Vista explodida: carenagem e chassi


### 16.1 Vista Superior (Top View)

```
                                FRENTE
                                  ↓
        ┌──────────────────────────────────────────────┐  ─┐
        │                  HC-SR04                     │   │
        │                                              │   │
        │                   ESP32                      │   │
        │                                              │   │
        │                  PILHAS                      │   │  140 mm
        │                                              │   │
        │                 TB6612FNG                    │   │
        │                                              │   │
        │      [MOTOR ESQ]              [MOTOR DIR]    │   │
        └──────────────────────────────────────────────┘  ─┘
                                 TRÁS

        ├──────────────────── 220 mm ───────────────────┤
```

### 16.2 Vista Frontal (Front View)

```
              ┌──────────────────────────┐
              │         HC-SR04          │   ← sensor frontal
              ├──────────────────────────┤
              │                          │
              │      CORPO / CHASSI      │   ~35 mm (altura)
              │                          │
        (o)───┴──────────────────────────┴───(o)
      RODA MOTRIZ                        RODA MOTRIZ
       ESQUERDA                            DIREITA
```

### 16.3 Vista Traseira (Rear View)

```
              ┌──────────────────────────┐
              │                          │
              │      CORPO / CHASSI      │   ~35 mm (altura)
              │      (acesso interno)    │
        (o)───┴──────────────────────────┴───(o)
      RODA MOTRIZ                        RODA MOTRIZ
       ESQUERDA                            DIREITA
                        (△)
                   RODA CASTER
                (apoio traseiro)
```

### 16.4 Legenda

| Símbolo / Elemento | Descrição |
|---|---|
| HC-SR04 | Sensor de distância, posição frontal |
| ESP32 | Placa controladora, posição central-superior |
| TB6612FNG | Driver de motores, posição próxima aos motores |
| PILHAS | Fonte de alimentação, posição central-inferior |
| MOTOR ESQ / MOTOR DIR | Motores DC com caixa de redução, laterais traseiras |
| (o) RODA MOTRIZ | Rodas motrizes, laterais |
| (△) RODA CASTER | Roda de apoio, traseira |
| 220 mm × 140 mm | Dimensões planejadas do chassi (não finais) |

---

## 17. Considerações de Montagem

- A fiação entre o ESP32, a ponte H e os motores corre por dentro do corpo, pelos furos abertos na modelagem, evitando cabos aparentes e facilitando o fechamento das seções;
- O suporte de pilhas fica na região central e baixa do corpo, mantendo o centro de gravidade baixo e a estabilidade durante a locomoção;
- O HC-SR04 é instalado com visada livre na face frontal, sem obstrução — o furo do sensor foi previsto na modelagem;
- O corpo abre em três seções unidas por pinos de encaixe, garantindo acesso aos componentes internos para ajustes e manutenção (RFIS06);
- O alinhamento dos dois eixos de motor é garantido pela travessa interna modelada pela equipe; o desbalanceamento residual entre os motores é corrigido por software, pela página de calibração descrita na seção 24.6;
- As rodas motrizes são fixadas ao eixo do motor pelo extensor impresso: o encaixe precisa estar firme, sob pena de a roda girar em falso sobre o eixo.

---

## 18. Considerações para a Entrega Final

Situação de cada etapa prevista para a conclusão do projeto:

| Etapa | Status | Onde está documentada |
|---|---|---|
| Definição dos parâmetros técnicos pendentes | ✅ Concluída | Seção 8.2 |
| Modelagem 3D definitiva e impressão | ✅ Concluída | Seção 23 e [`Modelo 3d/`](<Modelo 3d/README.md>) |
| Confecção da carenagem | ✅ Concluída — integrada ao corpo impresso | Seção 15.1 |
| Montagem elétrica completa | ✅ Concluída | Seção 24 |
| Firmware do ESP32 (motores, sem fio e sensor) | ✅ Concluído | Seção 24 e [`Códigos/`](<Códigos/README.md>) |
| Testes funcionais | ✅ Concluídos | Seções 21 e 25 |
| Integração chassi + carenagem | ✅ Resolvida por unificação em peça única | Seção 14.2 |

---

## 19. Possíveis Melhorias Futuras

Três itens previstos como melhoria futura na concepção **já foram implementados** durante a execução:

| Item previsto | Situação |
|---|---|
| Controle de velocidade variável por PWM | ✅ Implementado — PWM de 1 kHz/8 bits, com velocidade máxima ajustável em tempo real pelos gatilhos R2/L2 |
| Aplicativo/interface via Wi-Fi | ✅ Implementado — página web servida pelo próprio ESP32 para calibração dos motores |
| Atualização de firmware sem cabo | ✅ Implementado — OTA pela rede Wi-Fi (não estava previsto originalmente) |

Permanecem como melhorias futuras:

- Adição de sensores complementares (linha, proximidade lateral) para ampliar a percepção do ambiente;
- Sistema de iluminação (LEDs) nos olhos, reforçando a caracterização visual do personagem;
- Substituição das pilhas por bateria recarregável, ganhando autonomia e corrente de pico;
- Motorização dos braços e da cabeça, que hoje são articulados mas apenas posicionáveis à mão;
- Telemetria na página web (distância, velocidade e tensão da bateria em tempo real);
- Medição instrumentada de peso, autonomia e corrente de operação (ver seção 25.4).

---

## 20. Aula 15 — Arquitetura Eletrônica: Diagrama de Blocos e Alimentação

> 🕐 **Registro histórico.** Esta seção e a seção 21 documentam a etapa de **validação em bancada**, feita com Arduino Uno e módulo Bluetooth HC-05, antes da migração para o ESP32. Elas não descrevem o robô entregue — a eletrônica final está na **seção 24**. São mantidas porque registram a evolução do projeto e os testes que fundamentaram as decisões seguintes.

Nesta etapa o grupo realizou a **montagem física de bancada** dos componentes eletrônicos, com o objetivo de validar o diagrama de blocos, o diagrama de alimentação e a pinagem antes da integração definitiva no chassi.

### 20.1 Diagrama de Blocos (montagem de bancada)

```mermaid
flowchart TD
    HCSR04[Sensor Ultrassônico HC-SR04] -- TRIG/ECHO --> ARD[Arduino Uno]
    BT[Módulo Bluetooth HC-05] <-- comando --> ARD
    ARD -- IN1/IN2/IN3/IN4 + ENA/ENB --> L298N[Ponte H - L298N]
    L298N -- acionamento --> MOTORE[Motor Esquerdo]
    L298N -- acionamento --> MOTORD[Motor Direito]
    BAT[Bateria de teste] --> L298N
    BAT --> ARD
```

### 20.2 Diagrama de Alimentação (montagem de bancada)

```
BATERIA
   │
   ▼
PONTE H (L298N) ──► MOTORES
   │
   ▼
ARDUINO ──► SENSOR / BLUETOOTH
```

### 20.3 Registro fotográfico da montagem

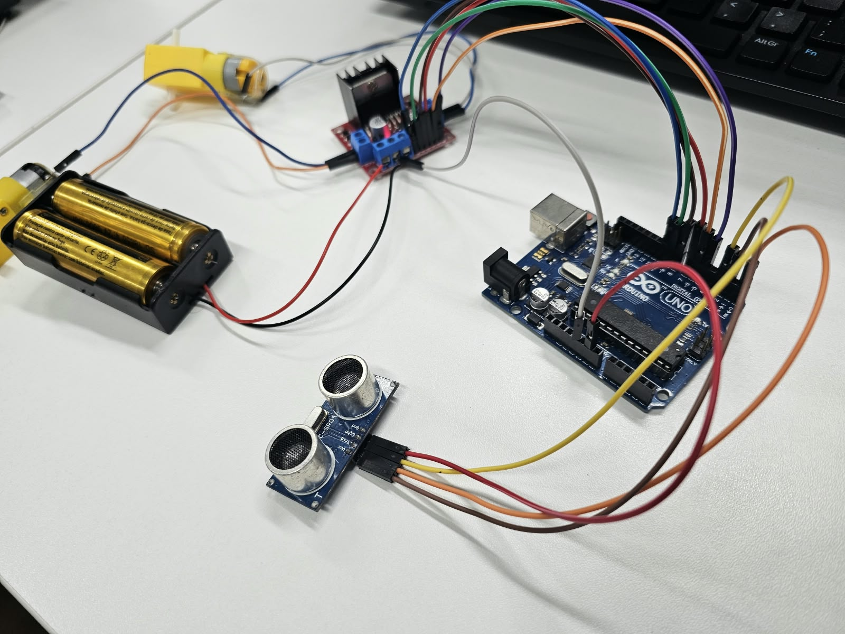
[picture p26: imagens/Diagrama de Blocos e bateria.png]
Diagrama de blocos e alimentação montado na bancada


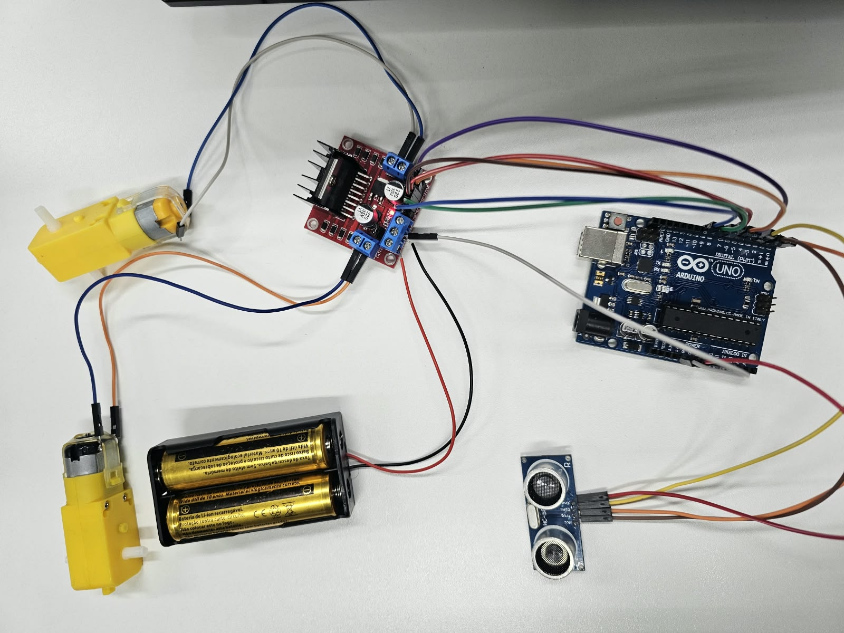
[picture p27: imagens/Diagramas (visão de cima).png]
Visão de cima da montagem: Arduino, ponte H, motores, sensor e bateria


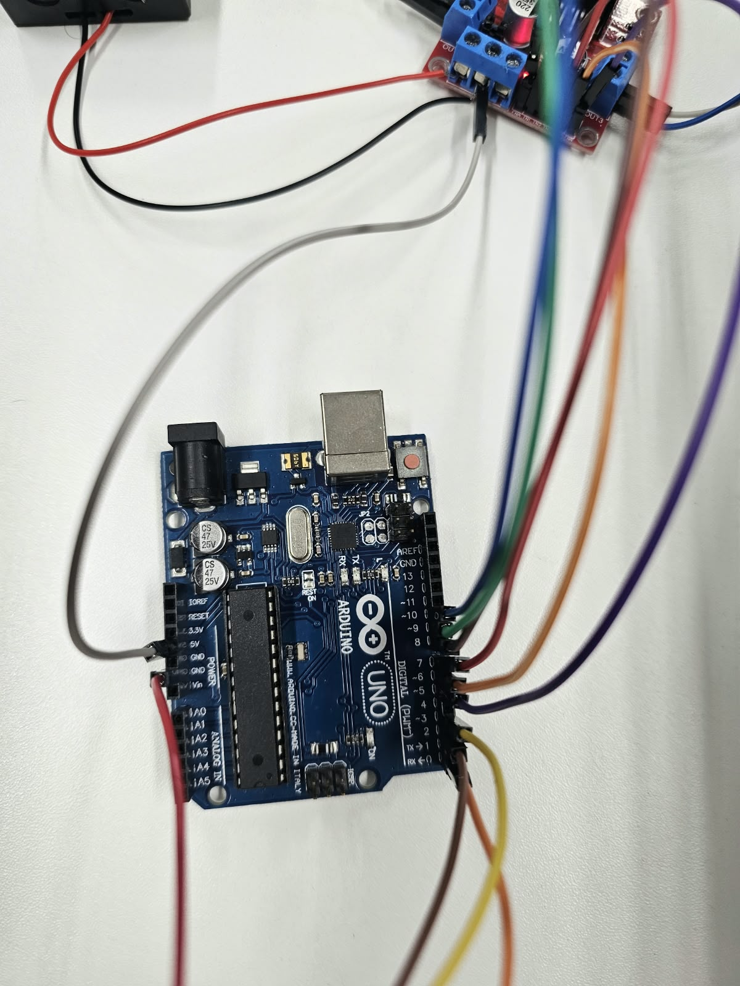
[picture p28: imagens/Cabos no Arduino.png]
Detalhe da organização dos cabos no Arduino


### 20.4 Pinagem validada na bancada

Durante a montagem, o grupo já testou e validou quais pinos serão utilizados para cada componente:

| Componente | Sinal | Pino (Arduino Uno — teste de bancada) |
|---|---|---|
| Ponte H (L298N) | IN1 (direção motor esquerdo) | D4 |
| Ponte H (L298N) | IN2 (direção motor esquerdo) | D7 |
| Ponte H (L298N) | IN3 (direção motor direito) | D8 |
| Ponte H (L298N) | IN4 (direção motor direito) | D12 |
| Ponte H (L298N) | ENA (PWM / velocidade motor esquerdo) | D5 |
| Ponte H (L298N) | ENB (PWM / velocidade motor direito) | D6 |
| Sensor HC-SR04 | TRIG | D2 |
| Sensor HC-SR04 | ECHO | D3 |

### 20.5 Observações importantes sobre a montagem de teste vs. versão final

> ⚠️ A montagem de bancada desta etapa foi feita com os componentes disponíveis no momento, **apenas para validar lógica, ligações e pinagem**. Os itens abaixo **não são os componentes definitivos** do projeto:

- **Placa controladora:** a montagem de bancada usou um **Arduino Uno**, mas a versão final do robô utilizará **ESP32** (conforme já definido na Ficha de Requisitos, seção 5). A pinagem acima será remapeada para os GPIOs do ESP32 na integração final.
- **Alimentação:** a montagem de bancada usou uma **bateria** (par de células recarregáveis) apenas por estarem disponíveis para o teste rápido. Na versão final do projeto será utilizada **pilha** (não recarregável), conforme já definido na Ficha de Requisitos (seção 5) e no Diagrama de Alimentação.

---

## 21. Aula 16 — Programação e Testes Iniciais

Com a pinagem validada na Aula 15, o grupo avançou para os testes de programação, seguindo a lógica de **programação modular** e **teste incremental** apresentada em aula: motor a motor, depois movimentos, depois sensor, depois comunicação sem fio.

### 21.1 Teste — Controle sem fio via Bluetooth

O grupo testou o controle remoto do carrinho via **módulo Bluetooth (HC-05)**, comandado por um aplicativo de controle (gamepad) no celular. O teste **funcionou**: o carrinho respondeu corretamente aos comandos enviados pelo app (frente, trás, esquerda, direita).

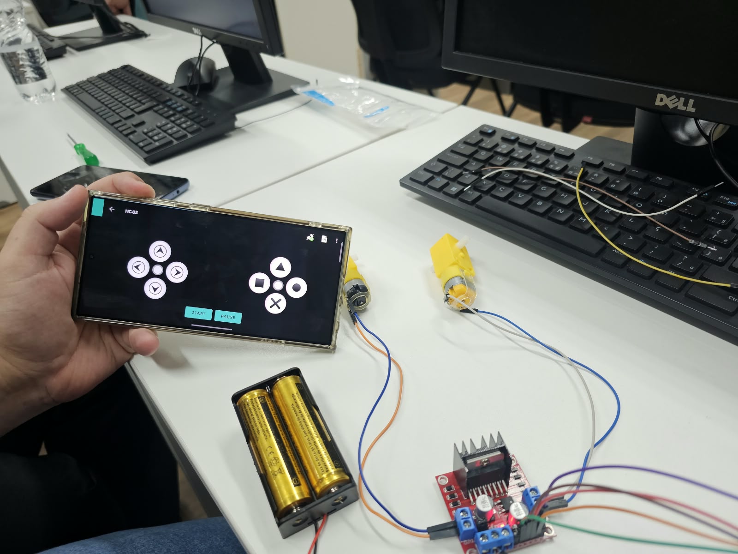
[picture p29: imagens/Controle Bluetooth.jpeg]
Controle do carrinho via aplicativo Bluetooth no celular


🎥 Vídeo do teste: [Controle Bluetooth.mp4](<vídeo/Controle Bluetooth.mp4>) *(o link abre o player de vídeo do próprio GitHub — veja a observação sobre reprodução do vídeo na seção 21.3)*

**Código utilizado no teste** (arquivo [`Códigos/testes-aula16/Motor + Bluetooth.ino`](<Códigos/testes-aula16/Motor + Bluetooth.ino>), testado em Arduino Uno + L298N + HC-SR04 + HC-05):

```cpp
/*
  Carrinho WALL-E — teste de bancada: Arduino Uno + L298N + HC-SR04 + HC-05 (Bluetooth clássico)

  Controle pelo app "Arduino Bluetooth Controller" (Giumig / com.giumig.apps.bluetoothserialmonitor)
  ou qualquer outro app que envie os caracteres F / B / L / R / S por Bluetooth clássico (SPP).

  IMPORTANTE: o app "BLE Controller" (que vocês baixaram antes) NÃO funciona com o HC-05 —
  o HC-05 comum usa Bluetooth clássico (SPP), não BLE. Por isso o app certo aqui é o
  "Arduino Bluetooth Controller" (funciona com HC-05/HC-06).

  Comandos recebidos via Bluetooth:
    F = frente   B = trás   L = esquerda   R = direita   S = parar (padrão quando solta o botão)

  A parada por obstáculo (HC-SR04) continua ativa: mesmo que o comando seja "F" (frente),
  se detectar algo perto, o carrinho para sozinho.
*/

#include <SoftwareSerial.h>

// HC-05: usamos SoftwareSerial em vez dos pinos 0/1, assim não precisa desconectar
// nada na hora de gravar o código pelo USB.
SoftwareSerial BT(11, 12); // pino 11 = RX do Arduino (liga no TXD do HC-05)
                            // pino 12 = TX do Arduino (liga no RXD do HC-05, via divisor resistivo)
                            // NOTA: pino 12 é normalmente IN4, mas desativado pra este teste

// ---------- Pinos do L298N (motores) ----------
const int IN1 = 4;
const int IN2 = 7;
const int IN3 = 8;
// const int IN4 = 12;  // DESATIVADO NESTE TESTE: pino 12 está sendo usado pelo HC-05 (TX)
const int ENA = 5; // PWM
const int ENB = 6; // PWM

// ---------- Pinos do HC-SR04 ----------
const int TRIG = 2;
const int ECHO = 3;

// ---------- Parâmetros ----------
const int VELOCIDADE = 200;
const float DISTANCIA_MINIMA_CM = 15.0;

char comando = 'S';

void setup() {
  pinMode(IN1, OUTPUT);
  pinMode(IN2, OUTPUT);
  pinMode(IN3, OUTPUT);
  // pinMode(IN4, OUTPUT);  // desativado neste teste (pino 12 = HC-05 TX)
  pinMode(ENA, OUTPUT);
  pinMode(ENB, OUTPUT);
  pinMode(TRIG, OUTPUT);
  pinMode(ECHO, INPUT);

  Serial.begin(9600);  // Serial Monitor (USB) - continua livre, não conflita com o BT
  BT.begin(9600);       // baud padrão da maioria dos módulos HC-05 (confirme com AT+UART?)

  parar();
  Serial.println("Pronto. Aguardando comandos via Bluetooth (F/B/L/R/S)...");
}

void loop() {
  if (BT.available()) {
    comando = BT.read();
    Serial.print("Comando recebido: ");
    Serial.println(comando);
  }

  float distancia = lerDistanciaCM();
  bool obstaculo = (distancia > 0 && distancia < DISTANCIA_MINIMA_CM);

  switch (comando) {
    case 'F':
      if (obstaculo) {
        parar();
        Serial.println("Obstaculo detectado - avanco bloqueado");
      } else {
        frente();
      }
      break;
    case 'B':
      tras();
      break;
    case 'L':
      esquerda();
      break;
    case 'R':
      direita();
      break;
    case 'S':
    default:
      parar();
      break;
  }

  delay(50);
}

// =====================================================================
// Funções de movimento
// =====================================================================

void frente() {
  digitalWrite(IN1, HIGH);
  digitalWrite(IN2, LOW);
  digitalWrite(IN3, HIGH);
  // digitalWrite(IN4, LOW);  // desativado neste teste (pino 12 = HC-05 TX)
  analogWrite(ENA, VELOCIDADE);
  analogWrite(ENB, VELOCIDADE);
}

void tras() {
  digitalWrite(IN1, LOW);
  digitalWrite(IN2, HIGH);
  digitalWrite(IN3, LOW);
  // digitalWrite(IN4, HIGH);  // desativado neste teste (pino 12 = HC-05 TX)
  analogWrite(ENA, VELOCIDADE);
  analogWrite(ENB, VELOCIDADE);
}

void esquerda() {
  digitalWrite(IN1, LOW);
  digitalWrite(IN2, HIGH);
  digitalWrite(IN3, HIGH);
  // digitalWrite(IN4, LOW);  // desativado neste teste (pino 12 = HC-05 TX)
  analogWrite(ENA, VELOCIDADE);
  analogWrite(ENB, VELOCIDADE);
}

void direita() {
  digitalWrite(IN1, HIGH);
  digitalWrite(IN2, LOW);
  digitalWrite(IN3, LOW);
  // digitalWrite(IN4, HIGH);  // desativado neste teste (pino 12 = HC-05 TX)
  analogWrite(ENA, VELOCIDADE);
  analogWrite(ENB, VELOCIDADE);
}

void parar() {
  digitalWrite(IN1, LOW);
  digitalWrite(IN2, LOW);
  digitalWrite(IN3, LOW);
  // digitalWrite(IN4, LOW);  // desativado neste teste (pino 12 = HC-05 TX)
  analogWrite(ENA, 0);
  analogWrite(ENB, 0);
}

// =====================================================================
// Sensor ultrassônico HC-SR04
// =====================================================================

float lerDistanciaCM() {
  digitalWrite(TRIG, LOW);
  delayMicroseconds(2);
  digitalWrite(TRIG, HIGH);
  delayMicroseconds(10);
  digitalWrite(TRIG, LOW);

  long duracao = pulseIn(ECHO, HIGH, 30000);
  if (duracao == 0) {
    return -1;
  }
  return duracao * 0.0343 / 2.0;
}
```

### 21.2 Teste — Motor + Sensor de Aproximação

O grupo também testou a integração entre os motores e o **sensor ultrassônico HC-SR04**. Nesse teste, o carrinho anda para frente continuamente e **os motores param automaticamente quando o sensor detecta um objeto próximo**, validando o comportamento esperado pelos requisitos RF05 (detecção de obstáculos) e RF06 (interrupção do movimento ao detectar obstáculo).

🎥 Vídeo do teste: [Motor + Sensor de Aproximação.mp4](<vídeo/Motor + Sensor de Aproximação.mp4>) *(o link abre o player de vídeo do próprio GitHub — veja a observação sobre reprodução do vídeo na seção 21.3)*

No vídeo é possível observar os motores parando assim que o carrinho se aproxima do objeto.

**Código utilizado no teste** (arquivo [`Códigos/testes-aula16/Motor + Sensor de Aproximacao.ino`](<Códigos/testes-aula16/Motor + Sensor de Aproximacao.ino>), testado em Arduino Uno + L298N + pilhas AA):

```cpp
/*
  Carrinho Robótico WALL-E — teste de motores + sensor (Arduino Uno + L298N)

  Baseado na montagem: Arduino Uno + módulo L298N + 2 motores DC + 4x pilhas AA
  (mesma montagem da imagem de referência), com o sensor HC-SR04 adicionado.

  Comportamento: o carrinho anda para frente continuamente e PARA automaticamente
  quando o HC-SR04 detecta um objeto mais perto que DISTANCIA_MINIMA_CM.

  Este código NÃO tem controle remoto (Bluetooth/app) — é só o teste de
  motores + sensor. Dá pra somar o controle remoto depois, em cima disso.
*/

// ---------- Pinos do L298N (motores) ----------
const int IN1 = 4;   // direção motor esquerdo
const int IN2 = 7;   // direção motor esquerdo
const int IN3 = 8;   // direção motor direito
const int IN4 = 12;  // direção motor direito
const int ENA = 5;   // velocidade motor esquerdo (PWM)
const int ENB = 6;   // velocidade motor direito (PWM)

// ---------- Pinos do sensor HC-SR04 ----------
const int TRIG = 2;
const int ECHO = 3;
// No Arduino Uno NÃO precisa de divisor resistivo no ECHO — a lógica do Uno já é 5V,
// igual ao HC-SR04 (isso só é necessário no ESP32, que trabalha em 3.3V).

// ---------- Parâmetros ajustáveis ----------
const int VELOCIDADE = 200;              // 0-255
const float DISTANCIA_MINIMA_CM = 15.0;  // ajustar depois de testar na prática

void setup() {
  pinMode(IN1, OUTPUT);
  pinMode(IN2, OUTPUT);
  pinMode(IN3, OUTPUT);
  pinMode(IN4, OUTPUT);
  pinMode(ENA, OUTPUT);
  pinMode(ENB, OUTPUT);
  pinMode(TRIG, OUTPUT);
  pinMode(ECHO, INPUT);

  Serial.begin(9600);
  parar();
  Serial.println("Pronto. Andando para frente ate encontrar um obstaculo.");
}

void loop() {
  float distancia = lerDistanciaCM();

  Serial.print("Distancia: ");
  Serial.print(distancia);
  Serial.println(" cm");

  if (distancia > 0 && distancia < DISTANCIA_MINIMA_CM) {
    parar();
    Serial.println("Objeto detectado - motores parados");
  } else {
    frente();
  }

  delay(100); // pequena pausa entre leituras
}

// =====================================================================
// Funções de movimento
// =====================================================================

void frente() {
  digitalWrite(IN1, HIGH);
  digitalWrite(IN2, LOW);
  digitalWrite(IN3, HIGH);
  digitalWrite(IN4, LOW);
  analogWrite(ENA, VELOCIDADE);
  analogWrite(ENB, VELOCIDADE);
}

void tras() {
  digitalWrite(IN1, LOW);
  digitalWrite(IN2, HIGH);
  digitalWrite(IN3, LOW);
  digitalWrite(IN4, HIGH);
  analogWrite(ENA, VELOCIDADE);
  analogWrite(ENB, VELOCIDADE);
}

void esquerda() {
  // giro no proprio eixo
  digitalWrite(IN1, LOW);
  digitalWrite(IN2, HIGH);
  digitalWrite(IN3, HIGH);
  digitalWrite(IN4, LOW);
  analogWrite(ENA, VELOCIDADE);
  analogWrite(ENB, VELOCIDADE);
}

void direita() {
  digitalWrite(IN1, HIGH);
  digitalWrite(IN2, LOW);
  digitalWrite(IN3, LOW);
  digitalWrite(IN4, HIGH);
  analogWrite(ENA, VELOCIDADE);
  analogWrite(ENB, VELOCIDADE);
}

void parar() {
  digitalWrite(IN1, LOW);
  digitalWrite(IN2, LOW);
  digitalWrite(IN3, LOW);
  digitalWrite(IN4, LOW);
  analogWrite(ENA, 0);
  analogWrite(ENB, 0);
}

// =====================================================================
// Sensor ultrassônico HC-SR04
// =====================================================================

float lerDistanciaCM() {
  digitalWrite(TRIG, LOW);
  delayMicroseconds(2);
  digitalWrite(TRIG, HIGH);
  delayMicroseconds(10);
  digitalWrite(TRIG, LOW);

  long duracao = pulseIn(ECHO, HIGH, 30000); // timeout 30ms

  if (duracao == 0) {
    return -1; // sem leitura valida
  }

  return duracao * 0.0343 / 2.0;
}
```

### 21.3 Como assistir aos vídeos e onde está o código

- **Vídeo:** o GitHub não reproduz vídeo diretamente dentro da página do `Documentacao.md` (markdown não dá suporte a player embutido/autoplay por segurança). Ao clicar em um dos links de vídeo acima, o GitHub abre a página do arquivo (`.mp4`) dentro do repositório, e nessa página o **próprio GitHub exibe um player nativo com botão de play** — não é necessário baixar o arquivo, só clicar em play na página que abrir.
- **Código:** os arquivos `.ino` usados nesses testes estão versionados em [`Códigos/testes-aula16/`](<Códigos/testes-aula16>), além de reproduzidos nesta documentação (seções 21.1 e 21.2). O firmware **definitivo**, que roda no robô entregue, é outro: [`Códigos/PS5_ESP32_Bluepad32.ino`](<Códigos/PS5_ESP32_Bluepad32.ino>), descrito na seção 24.

### 21.4 Observação sobre a placa utilizada nos testes

Assim como na Aula 15, os testes de programação desta etapa (Bluetooth e sensor) foram realizados em **Arduino Uno**, por ser a placa disponível para os testes rápidos de bancada.

✅ **A migração foi concluída.** A lógica validada aqui — movimento diferencial, leitura do HC-SR04, parada por proximidade e recepção de comandos sem fio — foi portada para o **ESP32**, e ampliada com PWM por rampa, controle por gamepad PS5, calibração via web e atualização OTA. O resultado está documentado na seção 24 e a comparação entre as duas versões, na seção 26.

---

## 22. Planejamento e Gestão do Projeto

Esta documentação técnica cobre a concepção física e funcional do robô. O planejamento e a gestão da execução (cronograma, priorização, tarefas e custos) ficam na pasta [`Organização/`](<Organização/README.md>), com os seguintes arquivos:

| Arquivo | Caminho | O que é |
|---|---|---|
| MVP | [`Organização/MVP.html`](<Organização/MVP.html>) | Definição do produto minimamente funcional, critérios de aceite e cronograma de marcos até a entrega do CP1 |
| MoSCoW | [`Organização/MoSCoW.html`](<Organização/MoSCoW.html>) | Priorização das funcionalidades em Must/Should/Could/Won't have |
| Backlog | [`Organização/Backlog.html`](<Organização/Backlog.html>) | Lista das 22 tarefas do projeto, com responsável, apoio, prioridade, pontos, prazo e critério de aceite |
| Dependências | [`Organização/Dependências.html`](<Organização/Dependências.html>) | Precedências entre tarefas, caminho crítico e riscos/dependências externas |
| Kanban | [`Organização/Kanban.html`](<Organização/Kanban.html>) | Quadro com a situação atual das tarefas (A fazer / Em andamento / Em validação / Concluído) |
| Planilha de custos | [`Organização/Planilha-de-custos.xlsx`](<Organização/Planilha-de-custos.xlsx>) | Planilha original (Excel) com materiais, links de compra, preços, quantidades e total estimado |
| Resumo da planilha de custos | [`Organização/Resumo-Planilha-de-custos.html`](<Organização/Resumo-Planilha-de-custos.html>) | Versão visual (HTML) da planilha de custos, agrupada por categoria, com status de compra de cada item |

---

## 23. Projeto Mecânico e Fabricação (versão final)

### 23.1 Do chassi plano ao corpo estrutural

A concepção previa duas peças: um chassi plano de 220 × 140 × 35 mm e uma carenagem por cima. Durante a modelagem ficou claro que o corpo do WALL-E — retangular, oco e com os conjuntos laterais — **já era um chassi**. Manter a placa embaixo dele duplicaria estrutura, adicionaria peso e subiria o centro de gravidade sem nenhum ganho.

A equipe partiu do modelo articulado **"WALL-E Robot - Articulated"**, de RoboDIYer (MakerWorld), e o converteu de figura decorativa em robô motorizado. No modelo original as esteiras giram livres, empurradas com a mão; não há previsão de motor, eletrônica ou alimentação.

### 23.2 Peças desenvolvidas pela equipe

| Peça | Dimensões | Função |
|---|---|---|
| `corpo-wall-e-furado.stl` | 204,4 × 126,0 × 77,7 mm | Corpo perfurado por operação booleana, abrindo passagem para os eixos dos motores, para a fiação e para a face do sensor |
| `extensor-de-eixo.stl` (×2) | 7,6 × 24,0 × 6,4 mm | **Peça-chave**: acopla o eixo do motor DC, que fica dentro do corpo, à roda motriz, que fica fora da lateral |
| `roda-boba-caster.stl` | 86,0 × 36,0 × 15,0 mm | Roda boba traseira — terceiro ponto de apoio, impede o robô de cabecear (RFIS05) |
| `travessa-interna.stl` | 98,0 × 25,0 × 14,0 mm | Sustenta e alinha os dois motores dentro do corpo, mantendo os eixos coaxiais |

Os STL estão em [`Modelo 3d/stl/`](<Modelo 3d/stl>) e o projeto completo do slicer, em [`Modelo 3d/Wall-E_Articulated(3).3mf`](<Modelo 3d/Wall-E_Articulated(3).3mf>).

### 23.3 Corte para impressão e acesso interno

O corpo montado tem 204 × 126 × 78 mm e não cabia em uma chapa com orientação adequada. Ele foi **seccionado em três partes** (`Body_B_B`, `Body_B_B_A`, `Body_B_B_B_B`) unidas por **7 pinos de encaixe** (`Conector-1` a `Conector-7`).

O corte trouxe um ganho não previsto: o corpo passou a **abrir**, dando acesso ao ESP32, à ponte H e às pilhas sem desmontar rodas, braços ou cabeça. Isso atende diretamente ao RFIS06.

Os renders das 16 chapas de impressão estão em [`Modelo 3d/renders/`](<Modelo 3d/renders>):

| | | | |
|---|---|---|---|
| Chapa 1 | Chapa 2 | Chapa 3 | Chapa 4 |
| Chapa 5 | Chapa 6 | Chapa 7 | Chapa 8 |

### 23.4 Distribuição real dos componentes

```
                         FRENTE
                           ↓
        ┌────────────────────────────────────┐
        │            HC-SR04                 │  ← embutido na tampa frontal
        │  ┌──────────────────────────────┐  │
  (O)   │  │  ESP32          PONTE H      │  │   (O)
  roda  │  │                              │  │   roda   ← rodas de borracha
  motriz│  │  MOTOR ESQ      MOTOR DIR    │  │   motriz    no eixo dos motores
        │  │    (travessa interna)        │  │
        │  │  SUPORTE 6x PILHAS AA        │  │
        │  └──────────────────────────────┘  │
        └────────────────────────────────────┘
          ╲___ conjuntos laterais impressos ___╱
                 (apoio no piso)
                          TRÁS

        ├─────────── 204,4 mm ───────────┤      altura: 77,7 mm
```

- **HC-SR04**: embutido na tampa frontal, com visada livre e os dois transdutores aparentes;
- **ESP32 e ponte H**: região interna, acessíveis ao abrir a tampa frontal;
- **Motores**: região central-baixa, presos pela travessa interna, com os eixos saindo pelas laterais através dos furos;
- **Rodas motrizes**: de borracha, fixadas aos eixos dos motores pelos extensores impressos;
- **Pilhas**: região central-baixa, mantendo o centro de gravidade baixo;
- **Conjuntos laterais impressos**: apoiam o robô no piso e reproduzem visualmente as esteiras do personagem.

### 23.5 Parâmetros de impressão

Bambu Lab A1, bico 0,4 mm, perfil 0.20 mm Standard, 2 paredes, 15% de preenchimento, suporte em árvore, 16 chapas, em PLA (amarelo, preto, prata, vermelho e cinza).

> O projeto do slicer herdou do modelo original as peças de esteira (`Track x2`) e um perfil de TPU 95A. Essas peças **não fazem parte do robô entregue**, que usa rodas de borracha acopladas aos eixos dos motores.

### 23.6 Versões do modelo

| Versão | O que mudou |
|---|---|
| v1 | Modelo base importado, sem alterações |
| v2 | `Wall-E_Articulated(2).3mf` — corte do corpo e primeiros furos |
| v3 | `Wall-E_Articulated(3).3mf` — **atual**: furação final, extensor de eixo, roda boba, travessa interna e reorganização das 16 chapas |

O encadeamento está registrado dentro do próprio arquivo: cada peça carrega o metadado `source_file` apontando para a versão anterior.

### 23.7 Acabamento

O modelo impresso, cru, sai monocromático e liso. O acabamento aplicado pela equipe é o que aproxima o robô do personagem do filme:

| Elemento | Descrição |
|---|---|
| Pintura de desgaste | Manchas de ferrugem e sujeira aplicadas no corpo, nos braços e na cabeça, simulando o aspecto envelhecido do WALL-E |
| Faixa preta texturizada | Aplicada no topo e nas laterais superiores do corpo |
| Adesivos impressos | Logotipo "WALL·E" na tampa frontal, painel "NÍVEL DE CARREGAMENTO SOLAR" na face superior, etiqueta de advertência na lateral e faixas de perigo no braço |
| Impressão multicolor | Corpo em amarelo, cabeça e braços em cinza, conjuntos laterais e painel em preto, detalhes em vermelho |

O resultado está nas fotos da seção 28.

---

## 24. Hardware, Eletrônica e Firmware (versão final)

### 24.1 Visão geral

O robô entregue roda o firmware [`Códigos/PS5_ESP32_Bluepad32.ino`](<Códigos/PS5_ESP32_Bluepad32.ino>) em um **ESP32 Dev Module**. Ele recebe comandos de um **controle PS5 DualSense** por Bluetooth clássico, aciona dois motores DC através de uma **ponte H dupla** e usa um **HC-SR04** como trava de segurança contra colisão frontal.

### 24.2 Pinagem (ESP32 — versão final)

| Componente | Sinal | GPIO | Observação |
|---|---|---|---|
| Ponte H | IN1 — Motor A (esquerdo) | **26** | PWM, canal LEDC 0 |
| Ponte H | IN2 — Motor A (esquerdo) | **27** | PWM, canal LEDC 1 |
| Ponte H | IN3 — Motor B (direito) | **32** | PWM, canal LEDC 2 |
| Ponte H | IN4 — Motor B (direito) | **33** | PWM, canal LEDC 3 |
| HC-SR04 | TRIG | **4** | Saída |
| HC-SR04 | ECHO | **18** | Entrada |

Todos os quatro sinais da ponte H são gerados por PWM de **1 kHz com resolução de 8 bits**, através do periférico LEDC do ESP32 (canais 0 a 3).

> ⚠️ **O HC-SR04 é alimentado em 3,3 V**, e não em 5 V. Essa decisão elimina a necessidade de divisor resistivo no pino ECHO: alimentado em 5 V, o sensor devolveria 5 V no ECHO e danificaria o GPIO do ESP32, que é tolerante apenas a 3,3 V. A 3,3 V o sensor funciona com alcance ligeiramente menor, suficiente para os 20 cm de detecção usados no projeto.

> **Polaridade do Motor B.** Os dois motores ficam montados espelhados no corpo, o que faz um deles girar ao contrário do outro para o mesmo sinal. Em vez de reinverter os fios, a correção foi feita **em software**: a função `aplicaMotorB()` inverte a ordem dos canais PWM. Trocar os fios do motor B na ponte H quebra esse pareamento.

### 24.3 Diagrama de conexões

```mermaid
flowchart LR
    BAT["BATERIA<br>com chave liga/desliga"]
    ESP["ESP32 Dev Module"]
    PH["PONTE H - L298N<br>jumpers ENA/ENB fechados"]
    ME["MOTOR ESQUERDO (A)"]
    MD["MOTOR DIREITO (B)"]
    SENSOR["HC-SR04"]

    BAT -- "+ e - para +12V e GND" --> PH
    PH -- "+5V para VIN" --> ESP

    ESP -- "GPIO26 para IN1" --> PH
    ESP -- "GPIO27 para IN2" --> PH
    ESP -- "GPIO32 para IN3" --> PH
    ESP -- "GPIO33 para IN4" --> PH

    PH -- "OUT1 e OUT2" --> ME
    PH -- "OUT3 e OUT4" --> MD

    ESP -- "GPIO4 para TRIG" --> SENSOR
    SENSOR -- "ECHO para GPIO18" --> ESP
    ESP -- "3V3 para VCC" --> SENSOR
    ESP -- "GND para GND" --> SENSOR
```

**Resumo das ligações:**

| De | Para | Função |
|---|---|---|
| ESP32 GPIO26 | L298N IN1 | Sentido/velocidade do motor A |
| ESP32 GPIO27 | L298N IN2 | Sentido/velocidade do motor A |
| ESP32 GPIO32 | L298N IN3 | Sentido/velocidade do motor B |
| ESP32 GPIO33 | L298N IN4 | Sentido/velocidade do motor B |
| ESP32 GPIO4 | HC-SR04 TRIG | Disparo do pulso ultrassônico |
| ESP32 GPIO18 | HC-SR04 ECHO | Retorno do eco |
| ESP32 3V3 | HC-SR04 VCC | Alimentação do sensor (**não usar 5 V**) |
| ESP32 GND | HC-SR04 GND / L298N GND | Terra comum a todos os módulos |
| L298N OUT1/OUT2 | Motor esquerdo | Saída de potência |
| L298N OUT3/OUT4 | Motor direito | Saída de potência |
| Bateria (+/−) | L298N +12V / GND | Entrada de potência |
| L298N +5V | ESP32 VIN | Alimentação lógica do ESP32 pelo regulador da ponte H |

> ⚠️ **Os jumpers ENA e ENB do L298N ficam fechados.** O controle de velocidade é feito por PWM nas próprias entradas `IN1`–`IN4`, e não por pinos de *enable* separados. Se os jumpers forem removidos, os motores não giram.

> ⚠️ **O terra precisa ser comum** entre ESP32, ponte H e sensor. Sem isso, as leituras do HC-SR04 ficam erráticas e os motores respondem de forma imprevisível.

### 24.4 Alimentação

```
6x PILHAS AA -- 9 V nominais (suporte com chave)
   │
   ▼
PONTE H ──► MOTOR ESQUERDO
   │    └─► MOTOR DIREITO
   │
   ▼
ESP32 ──► HC-SR04 (3,3 V)
```

O conjunto de 6 pilhas AA fornece cerca de **9 V nominais** e alimenta a ponte H, que por sua vez entrega tensão regulada ao ESP32; o ESP32 alimenta o sensor em 3,3 V. A chave do suporte de pilhas é o liga/desliga geral do robô.

A escolha de 6 pilhas em vez de 4 não é detalhe: o L298N consome cerca de 2 V internamente entre a entrada e a saída de potência. Com 4 pilhas (6 V), sobrariam aproximadamente 4 V para os motores e o regulador interno ficaria no limite para alimentar o ESP32. Com 6 pilhas, os motores recebem tensão suficiente para manter torque sob carga e o regulador trabalha com folga.

### 24.5 Funcionamento do firmware

O `loop()` executa cinco tarefas a cada ciclo, sem nenhuma chamada bloqueante longa:

**1. Leitura do controle.** `BP32.update()` busca o estado do DualSense. Os eixos vêm na faixa de −511 a 512. O eixo Y do stick esquerdo tem o sinal invertido (empurrar para cima devolve valor negativo) e vira o comando de **avanço**; o eixo X do stick direito vira o comando de **giro**.

**2. Zona morta.** Valores abaixo de 80 unidades (~15% do curso) são zerados. Sem isso, o desgaste natural do analógico faria o robô andar sozinho parado.

**3. Mistura diferencial.** Os dois comandos viram potência de cada motor:

```cpp
int a = fr + gr;   // motor A (esquerdo)
int b = fr - gr;   // motor B (direito)
```

Só avanço → os dois motores giram juntos. Só giro → giram em sentidos opostos, e o robô roda sobre o próprio eixo. Combinados → curva aberta.

**4. Freio de segurança.** O sensor é lido a cada 60 ms, com timeout de 15 ms no `pulseIn` (~2,5 m de alcance) para nunca travar o loop esperando um eco que não vem. Se houver obstáculo a menos de 20 cm:

```cpp
bool objetoPerto = (distanciaCm >= 0 && distanciaCm < DISTANCIA_MIN_CM);
if (objetoPerto && fr > 0) fr = 0;   // corta SÓ o avanço
```

A ré e o giro continuam liberados — o robô nunca fica preso contra a parede.

**5. Rampa de aceleração.** Os valores calculados não vão direto ao motor: eles são a *meta*. A cada 15 ms, a potência atual se aproxima da meta em 12 unidades. Isso suaviza o arranque, evita o tranco que faz o robô empinar ou a roda patinar e reduz o pico de corrente sobre as pilhas.

**Ajuste de velocidade em tempo real.** Os gatilhos analógicos alteram o teto de velocidade sem recompilar: **R2** aumenta e **L2** reduz `velMax`, dentro dos limites de 80 a 255 (valor inicial: 200).

### 24.6 Calibração dos motores pela web

Dois motores DC nunca giram exatamente na mesma rotação sob a mesma tensão — o robô puxa para um lado ao tentar andar reto. Em vez de compensar isso com valores fixos no código, o firmware sobe um **servidor web** no próprio ESP32.

Acessando `http://<ip-do-esp32>/` pelo celular, na mesma rede Wi-Fi, aparecem dois sliders (30% a 100%) que aplicam um fator de correção a cada motor, e o valor atual do sensor de distância. Os valores são salvos na **memória não-volátil (NVS)** via `Preferences` e sobrevivem ao desligamento.

Endpoints: `/` (página), `/get` (estado em JSON), `/set?a=&b=` (grava os fatores).

### 24.7 Atualização OTA

Depois da primeira gravação por cabo, novas versões do firmware são enviadas pela rede Wi-Fi: o robô aparece no Arduino IDE em `Tools > Port` como `carrinho-esp32`. Isso evita abrir o corpo impresso a cada ajuste de código — o que, com o corpo fechado por pinos de encaixe e todo o conjunto montado, economizou bastante tempo.

> Requer **Partition Scheme com OTA** selecionado no Arduino IDE. Qualquer opção com "No OTA" no nome faz a atualização pela rede falhar.

### 24.8 Credenciais de rede

O SSID e a senha do Wi-Fi ficam em `Códigos/secrets.h`, que **não é versionado** (está no `.gitignore`). O repositório traz [`Códigos/secrets.h.example`](<Códigos/secrets.h.example>) como modelo: basta copiá-lo para `secrets.h` e preencher.

---

## 25. Testes, Problemas e Correções

### 25.1 Testes realizados

| # | Teste | Resultado | Evidência |
|---|---|---|---|
| T1 | Acionamento individual de cada motor (bancada) | ✅ Passou | Seção 20.3 |
| T2 | Movimento para frente, ré e curvas (bancada) | ✅ Passou | Seção 21 |
| T3 | Leitura do HC-SR04 e parada automática (bancada) | ✅ Passou | Seção 21.2 + vídeo |
| T4 | Controle remoto sem fio, via HC-05 e app (bancada) | ✅ Passou | Seção 21.1 + vídeo |
| T5 | Pareamento do DualSense com o ESP32 via Bluepad32 | ✅ Passou | Seção 25.2 |
| T6 | Controle diferencial com os dois sticks | ✅ Passou | — |
| T7 | Freio de segurança a 20 cm, com ré e giro liberados | ✅ Passou | — |
| T8 | Calibração dos motores pela página web | ✅ Passou | Seção 24.6 |
| T9 | Atualização de firmware por OTA | ✅ Passou | Seção 24.7 |
| T10 | Locomoção com o corpo montado, fechado e com o acabamento aplicado | ✅ Passou | Seção 28.3 |

### 25.2 Problemas encontrados e correções

| # | Problema | Causa | Correção adotada |
|---|---|---|---|
| P1 | App "BLE Controller" não conectava no módulo HC-05 | HC-05 usa Bluetooth **clássico** (SPP), não BLE | Troca para o app "Arduino Bluetooth Controller", compatível com SPP |
| P2 | Um motor girava ao contrário do outro com o mesmo comando | Motores montados espelhados no corpo | Inversão da ordem dos canais PWM na função `aplicaMotorB()`, em vez de reinverter os fios |
| P3 | Robô não andava reto — puxava sempre para o mesmo lado | Diferença de rotação natural entre dois motores DC | Fatores de correção por motor, ajustáveis pela página web e salvos em NVS (seção 24.6) |
| P4 | Robô se movia sozinho com os sticks em repouso | Ruído/desgaste do potenciômetro do analógico | Zona morta de 80 unidades (~15%) aplicada aos dois eixos |
| P5 | Tranco no arranque, com o robô empinando e a roda patinando | Aplicação de PWM máximo instantaneamente | Rampa de aceleração: 12 unidades a cada 15 ms |
| P6 | Loop travava por instantes quando não havia obstáculo à frente | `pulseIn` esperava o eco até o timeout padrão | Timeout reduzido para 15 ms (~2,5 m) e leitura limitada a 1 a cada 60 ms |
| P7 | Risco de dano ao GPIO do ESP32 pelo pino ECHO | HC-SR04 em 5 V devolve 5 V no ECHO; o ESP32 tolera 3,3 V | Sensor alimentado em 3,3 V, dispensando divisor resistivo |
| P8 | Robô cabeceava ao frear | Apoio concentrado apenas nas duas rodas motrizes laterais | Modelagem do suporte de roda boba, dando pontos de apoio adicionais |
| P9 | Corpo montado não cabia na mesa de impressão | 204 × 126 × 78 mm | Corte em três seções com 7 pinos de encaixe — que ainda resolveu o acesso interno |
| P10 | Esteiras impressas do modelo original não transmitiam torque de forma confiável | Conjunto projetado para girar livre, empurrado à mão, e não para receber tração de motor | Substituição por rodas de borracha acopladas ao eixo pelo extensor impresso; os conjuntos laterais passaram a servir de apoio e elemento visual |
| P11 | Reabrir o corpo a cada ajuste de firmware era inviável | Corpo fechado por encaixe, com todo o conjunto montado | Implementação de atualização OTA via Wi-Fi |
| P12 | Controle não reconectava, tentando parear com dispositivo antigo | Chaves de pareamento antigas guardadas no ESP32 | `BP32.forgetBluetoothKeys()` — deixada comentada no código, para uso pontual |

### 25.3 Resultado final

O robô cumpre todos os requisitos funcionais definidos:

| Requisito | Situação |
|---|---|
| RF01 — movimentar-se para frente | ✅ |
| RF02 — movimentar-se para trás | ✅ |
| RF03 — curvas por controle diferencial | ✅ Inclui giro sobre o próprio eixo |
| RF04 — comandos por controle remoto sem fio | ✅ PS5 DualSense via Bluetooth |
| RF05 — detectar obstáculos | ✅ HC-SR04, leitura a cada 60 ms |
| RF06 — interromper/modificar o movimento ao detectar obstáculo | ✅ Bloqueio de avanço a 20 cm, com ré e giro liberados |

### 25.4 Limitações conhecidas

- **Peso, autonomia e corrente de operação não foram medidos** por falta de instrumentação — permanecem como parâmetros não caracterizados;
- O alcance do sensor é reduzido por operar em 3,3 V, o que é irrelevante para a distância de 20 cm utilizada;
- Os braços, a cabeça e a tampa frontal são articulados, mas **posicionáveis apenas à mão** — não são motorizados;
- Os conjuntos laterais impressos são **apoio e elemento visual**, não tracionam: a locomoção é toda feita pelas duas rodas de borracha;
- A página de calibração e o OTA dependem da rede Wi-Fi configurada em `secrets.h`; fora dela, o robô continua pilotável, mas sem esses dois recursos.

---

## 26. Evolução do Projeto e Decisões

| # | Decisão | Motivo |
|---|---|---|
| D1 | Arduino Uno **apenas** para bancada; ESP32 na versão final | O Uno não tem rádio integrado. O ESP32 traz Wi-Fi e Bluetooth no próprio chip, permitindo controle sem fio, OTA e página web sem hardware adicional |
| D2 | Abandono do módulo HC-05 | Com o ESP32, o Bluetooth passou a ser nativo — o módulo externo virou peça redundante ocupando espaço e pinos |
| D3 | Controle PS5 DualSense no lugar do app de celular | Sticks analógicos dão controle proporcional de velocidade e curva, impossível com os botões F/B/L/R do app. Também libera o celular para a página de calibração |
| D4 | Uso da biblioteca Bluepad32 | Mais estável que as alternativas baseadas em *spoof* de endereço MAC, e com suporte oficial ao DualSense |
| D5 | Eliminação do chassi plano | O corpo do WALL-E já era estrutura. Manter os dois duplicaria peso e subiria o centro de gravidade |
| D6 | Rodas de borracha no lugar das esteiras impressas | As esteiras do modelo original foram projetadas para girar livres, não para receber torque de motor. As rodas de borracha dão aderência e acoplamento confiáveis; os conjuntos laterais impressos permanecem como apoio e como elemento visual das esteiras do personagem |
| D7 | Correção de polaridade por software | Evita depender da ordem correta dos fios na montagem, que é fácil de errar ao fechar o corpo |
| D8 | Calibração por página web em vez de constante no código | Permite ajustar o robô no local da apresentação, sem notebook, cabo ou recompilação |
| D9 | Freio que bloqueia só o avanço | Uma parada total prenderia o robô contra o obstáculo, exigindo intervenção manual |
| D10 | `secrets.h` fora do versionamento | Impede que a senha do Wi-Fi vá para o repositório público |

---

## 27. Instruções de Uso

### 27.1 Ligar e pilotar

1. Ligue a chave do suporte de pilhas.
2. Coloque o DualSense em modo pareamento: segure **PS + Create** até o LED piscar rápido.
3. Aguarde o pareamento (alguns segundos). O robô já está pronto.
4. **Stick esquerdo (frente/trás)** — avanço e ré. **Stick direito (esquerda/direita)** — giro.
5. **R2** aumenta a velocidade máxima; **L2** reduz.
6. Ao aproximar-se de um obstáculo a menos de 20 cm, o avanço é bloqueado automaticamente. Use a ré ou o giro para sair.

### 27.2 Calibrar os motores

1. Conecte o celular à mesma rede Wi-Fi configurada em `secrets.h`.
2. Abra `http://<ip-do-esp32>/` — o IP é exibido no Serial Monitor (115200 baud) ao ligar.
3. Ande para a frente com o controle e reduza o slider do motor mais forte até o robô andar reto.
4. Os valores são salvos sozinhos e sobrevivem ao desligamento.

### 27.3 Gravar o firmware

1. Instale o pacote de placas **Bluepad32** no Arduino IDE.
2. Selecione `ESP32 Bluepad32 Arduino > ESP32 Dev Module`.
3. Em `Tools > Partition Scheme`, escolha uma opção **com OTA**.
4. Copie `Códigos/secrets.h.example` para `Códigos/secrets.h` e preencha o SSID e a senha da rede.
5. Grave por cabo USB na primeira vez. Depois disso, use OTA (`Tools > Port > carrinho-esp32`).

### 27.4 Se o controle não conectar

Descomente a linha `BP32.forgetBluetoothKeys();` no `setup()`, grave, ligue uma vez, e comente novamente. Isso apaga pareamentos antigos guardados no ESP32.

---

## 28. Evidências Finais

### 28.1 Fotos do robô finalizado

| Vista frontal | Vista três-quartos |
|---|---|
| Vista frontal | Vista três-quartos |

| Vista lateral | Vista traseira |
|---|---|
| Vista lateral | Vista traseira |

Na vista frontal aparecem os dois transdutores do **HC-SR04** embutidos na tampa, logo abaixo do painel de carregamento solar. Nas vistas laterais é possível ver a **roda motriz de borracha** saindo pela lateral do corpo e os **conjuntos laterais impressos** apoiando o robô no piso.

### 28.2 Eletrônica interna e acesso para manutenção

Compartimento frontal aberto, com a eletrônica à vista

A tampa frontal abre para baixo e expõe todo o conjunto: os **dois motores DC** alinhados pela travessa interna, a **placa de ligações** com os jumpers, o **suporte de pilhas** e o **HC-SR04** fixado na parte inferior da tampa. Nenhuma outra peça precisa ser removida — é a comprovação prática do requisito RFIS06.

### 28.3 Vídeos do funcionamento

Quatro registros do robô finalizado em operação, somando cerca de um minuto. Como o robô **só se move sob comando do controle**, todos eles são também demonstração do controle remoto sem fio em uso.

| Vídeo | Duração |
|---|---|
| [`vídeo/funcionamento-1.mp4`](<vídeo/funcionamento-1.mp4>) | 17 s |
| [`vídeo/funcionamento-2.mp4`](<vídeo/funcionamento-2.mp4>) | 10 s |
| [`vídeo/funcionamento-3.mp4`](<vídeo/funcionamento-3.mp4>) | 17 s |
| [`vídeo/funcionamento-4.mp4`](<vídeo/funcionamento-4.mp4>) | 14 s |

A demonstração específica do **sensor de aproximação** está no vídeo da etapa de bancada, [`vídeo/Motor + Sensor de Aproximação.mp4`](<vídeo/Motor + Sensor de Aproximação.mp4>) (seção 21.2), no qual os motores param automaticamente quando o HC-SR04 detecta um objeto à frente. A mesma lógica, com a distância mínima de 20 cm, está no firmware final (seção 24.5).

> O GitHub não reproduz vídeo dentro da página do Markdown. Ao clicar no link, o GitHub abre a página do arquivo `.mp4` e exibe um player nativo com botão de play.

### 28.4 Evidências das etapas anteriores

| Evidência | Arquivo |
|---|---|
| Montagem eletrônica de bancada | [`imagens/Diagrama de Blocos e bateria.png`](<imagens/Diagrama de Blocos e bateria.png>), [`imagens/Diagramas (visão de cima).png`](<imagens/Diagramas (visão de cima).png>), [`imagens/Cabos no Arduino.png`](<imagens/Cabos no Arduino.png>) |
| Controle sem fio (teste de bancada) | [`imagens/Controle Bluetooth.jpeg`](<imagens/Controle Bluetooth.jpeg>) e [`vídeo/Controle Bluetooth.mp4`](<vídeo/Controle Bluetooth.mp4>) |
| Sensor de aproximação (teste de bancada) | [`vídeo/Motor + Sensor de Aproximação.mp4`](<vídeo/Motor + Sensor de Aproximação.mp4>) |
| Renders das chapas de impressão | [`Modelo 3d/renders/`](<Modelo 3d/renders>) |
| Modelo 3D e STL das peças próprias | [`Modelo 3d/`](<Modelo 3d/README.md>) |
| Firmware final | [`Códigos/PS5_ESP32_Bluepad32.ino`](<Códigos/PS5_ESP32_Bluepad32.ino>) |

> 📋 **Observação.** Os dois arquivos de vídeo da etapa de bancada (`Controle Bluetooth.mp4` e `Motor + Sensor de Aproximação.mp4`) são atualmente **o mesmo arquivo duplicado**. O vídeo do segundo teste precisa ser reenviado.

---

**Documento:** Documentação Técnica — CP1
**Projeto:** Carrinho Robótico WALL-E
**Turma:** 4ESPY
**Última alteração em:** 16/09/2026

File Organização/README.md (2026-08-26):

# Organização do Projeto — Carrinho Robótico WALL-E

Esta pasta reúne os artefatos de planejamento e gestão do projeto, com entrega final prevista para **16 de setembro de 2026**.

## Entregáveis

- [MVP](MVP.html) — definição do produto minimamente funcional e da versão concluída;
- [MoSCoW](MoSCoW.html) — priorização das funcionalidades;
- [Backlog](Backlog.html) — tarefas, responsáveis, prazos e critérios de aceite;
- [Dependências](Dependências.html) — relações de precedência e caminho crítico;
- [Kanban](Kanban.html) — situação atual das atividades;
- [Planilha de custos](Planilha-de-custos.xlsx) — planilha original (Excel) com materiais, links, preços, quantidades e total estimado;
- [Resumo da planilha de custos](Resumo-Planilha-de-custos.html) — versão visual (HTML) da planilha, com totais, categorias e status de compra de cada item.

> MVP, MoSCoW, Backlog, Dependências e Kanban foram convertidos de Markdown para HTML para leitura mais visual; a planilha de custos original em Excel foi mantida ao lado do seu resumo em HTML.

## Equipe

| Integrante | Frente principal |
|---|---|
| Julia Azevedo Lins | Firmware, integração e documentação |
| Luis Gustavo Barreto Garrido | Documentação, gestão e evidências |
| Victor Hugo Aranda Forte | Modelagem e impressão 3D |
| Felipe Cortez | Montagem elétrica e mecânica |
| Guilherme Akio | Montagem elétrica e mecânica |

> O Kanban é um retrato do planejamento em 26/08/2026 e deve ser atualizado pela equipe durante a execução.

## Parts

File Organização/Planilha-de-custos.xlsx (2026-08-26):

CARRINHO ROBÓTICO WALL-E — PLANILHA DE CUSTOS
Estimativa para o CP1 • entrega em 16/09/2026 • preços consultados em 26/08/2026
Resumo | Valor |  | Indicador | Quantidade |  | Indicador | Valor
Total estimado | R$327.23 |  | Itens orçados | 14 |  | Reserva recomendada (10%) | R$32.72
 |  |  |  |  |  | Orçamento com reserva | R$359.95
Categoria | Item | Especificação | Quantidade | Preço unitário | Subtotal | Situação | Link da loja | Observação
Eletrônica | ESP32 DevKit | Wi-Fi + Bluetooth | 1.00 | R$54.90 | R$54.90 | Comprar/confirmar | https://www.robocore.net/wifi/esp32-wifi-bluetooth | Placa definitiva; confirmar modelo e pinagem
Eletrônica | Driver TB6612FNG | Ponte H dupla | 1.00 | R$29.90 | R$29.90 | Comprar/confirmar | https://lista.mercadolivre.com.br/tb6612fng | Substitui o L298N usado no teste
Sensor | HC-SR04 | Sensor ultrassônico 5 V | 1.00 | R$9.80 | R$9.80 | Já testado | https://www.robocore.net/produtos/sensor-de-distancia-ultrassonico-hc-sr04/ | Custo de reposição; proteger entrada Echo do ESP32
Mecânica | Motor TT + roda 68 mm | Motor DC 3–6 V com redução | 2.00 | R$18.90 | R$37.80 | Já testado/confirmar | https://www.mercadolivre.com.br/motor-dc-eletrico-36v-caixa-de-reducao-eixo-duplo--rodinha/up/MLBU770538214 | Duas unidades, uma por lado
Mecânica | Roda caster | Roda boba para chassi 2WD | 1.00 | R$12.90 | R$12.90 | Comprar/confirmar | https://lista.mercadolivre.com.br/roda-caster-robo | Confirmar altura em relação às rodas motrizes
Alimentação | Suporte para pilhas | 4×AA com chave liga/desliga | 1.00 | R$16.90 | R$16.90 | Comprar/confirmar | https://lista.mercadolivre.com.br/suporte-de-pilhas-para-protoboard | Confirmar tensão e capacidade antes da compra
Alimentação | Pilhas AA | Alcalinas | 4.00 | R$4.00 | R$16.00 | Comprar | https://lista.mercadolivre.com.br/pilhas-aa-alcalinas | Levar um segundo conjunto para contingência
Conexões | Jumpers | Kit 40 fios, 20 cm | 1.00 | R$19.90 | R$19.90 | Já disponível/confirmar | https://lista.mercadolivre.com.br/jumper-fio-40-20cm | Tipos macho-macho e macho-fêmea
Conexões | Protoboard ou placa perfurada | Base para interligações | 1.00 | R$14.90 | R$14.90 | Já disponível/confirmar | https://lista.mercadolivre.com.br/protoboard-400-pontos | Preferir placa perfurada na montagem final
Impressão 3D | Filamento PLA alocado | 0,25 kg de um rolo de 1 kg | 0.25 | R$104.90 | R$26.23 | Usar laboratório/comprar | https://lista.mercadolivre.com.br/filamento-pla | Custo proporcional; preço do rolo inteiro é R$ 104,90
Fixação | Parafusos, porcas e espaçadores | M2/M3 variados | 1.00 | R$18.00 | R$18.00 | Comprar/separar | https://lista.mercadolivre.com.br/kit-parafuso-m3-espacador | Ajustar após revisão do modelo 3D
Carenagem | Papel cartão/EVA e cola | Acabamento visual WALL-E | 1.00 | R$30.00 | R$30.00 | Comprar/separar | https://lista.mercadolivre.com.br/papel-cartao-eva-cola | Valor estimado conforme material escolhido
Acabamento | Tinta e adesivos | Cores e detalhes do personagem | 1.00 | R$25.00 | R$25.00 | Opcional | https://lista.mercadolivre.com.br/tinta-acrilica-artesanato | Item Could; retirar se houver restrição de orçamento
Contingência | Fita isolante e abraçadeiras | Organização e isolamento | 1.00 | R$15.00 | R$15.00 | Comprar/separar | https://lista.mercadolivre.com.br/fita-isolante-abracadeira | Não substituir conexões elétricas adequadas
Premissas e observações
• Valores são estimativas de reposição e não representam necessariamente o desembolso real, pois parte dos componentes já foi utilizada nos testes.
• Frete não incluído. Preços e disponibilidade podem mudar; confirmar antes da compra. O custo proporcional de PLA considera 250 g.
• O modelo definitivo das pilhas deve ser validado tecnicamente antes da compra. Links de busca foram usados quando o anúncio exato pode variar.

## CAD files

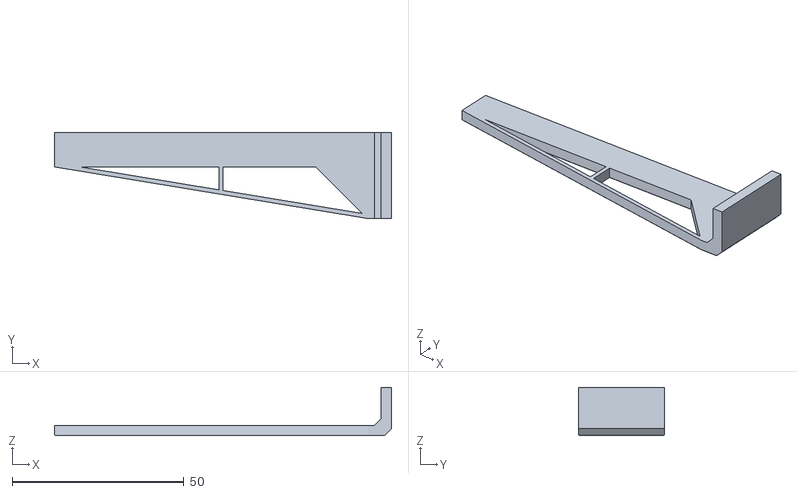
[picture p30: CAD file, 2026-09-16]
Modelo 3d/stl/travessa-interna.stl
98.0 x 25.0 x 14.0

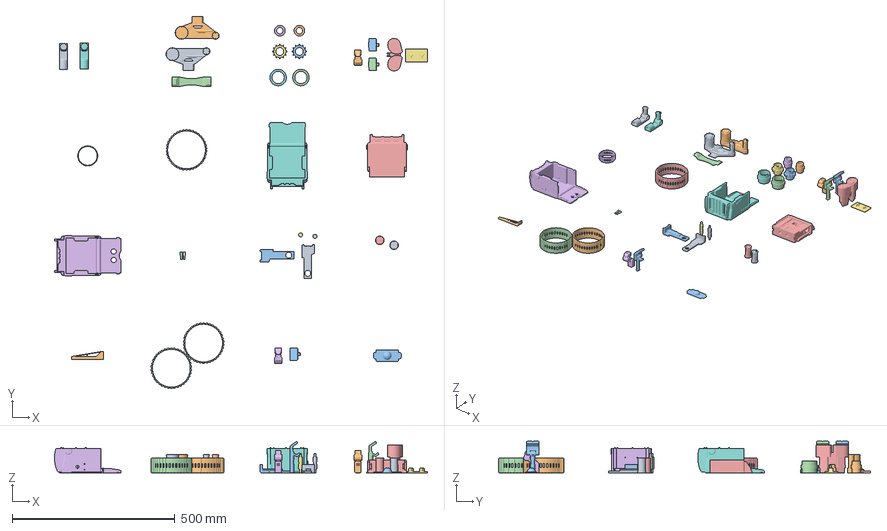
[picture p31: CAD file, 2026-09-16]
Modelo 3d/Wall-E_Articulated(3).3mf
1147.1 x 1144.0 x 97.1 mm
Left track frame.stl
Track x2.stl x 4
Forearm x2 x 3
Body_B_B_A
Neck.stl x 2
Rear piston x2.stl x 2
Body_B_B_B_B
Top left cover.stl
Right track frame.stl
Top right cover.stl
Bottom track support.stl
Drive mount x2.stl x 2
Front wheel x2.stl x 2
Geared wheel x2.stl x 2
Rear wheel x2.stl x 2
Panel.stl
Arm x2 x 2
Head.stl
Corpo de malha furado.stl
Estensor de eixo.stl x 2
Corpo2.stl
Roda boba.stl

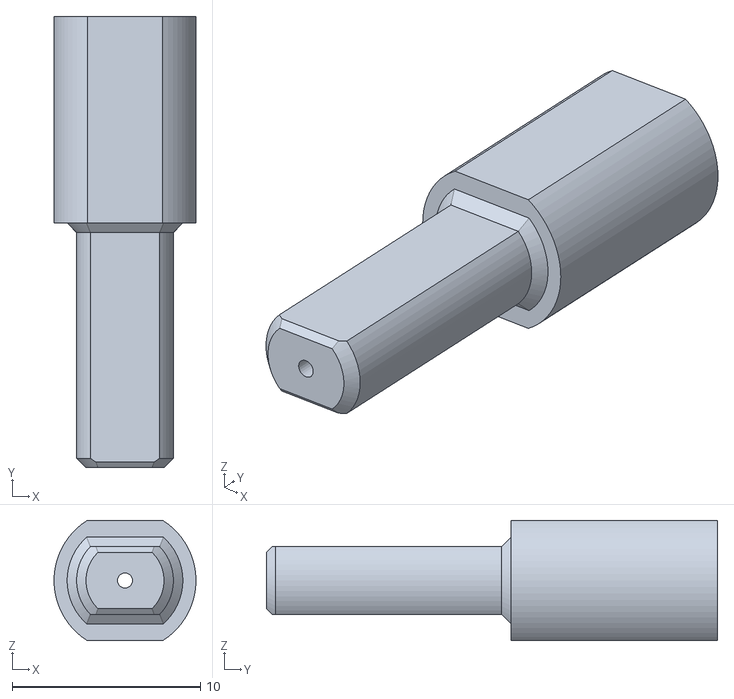
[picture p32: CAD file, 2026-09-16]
Modelo 3d/stl/extensor-de-eixo.stl
7.55 x 24.0 x 6.40

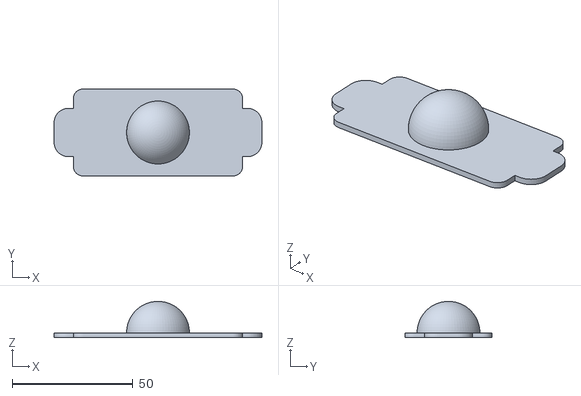
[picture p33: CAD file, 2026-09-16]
Modelo 3d/stl/roda-boba-caster.stl
86.0 x 36.0 x 15.0

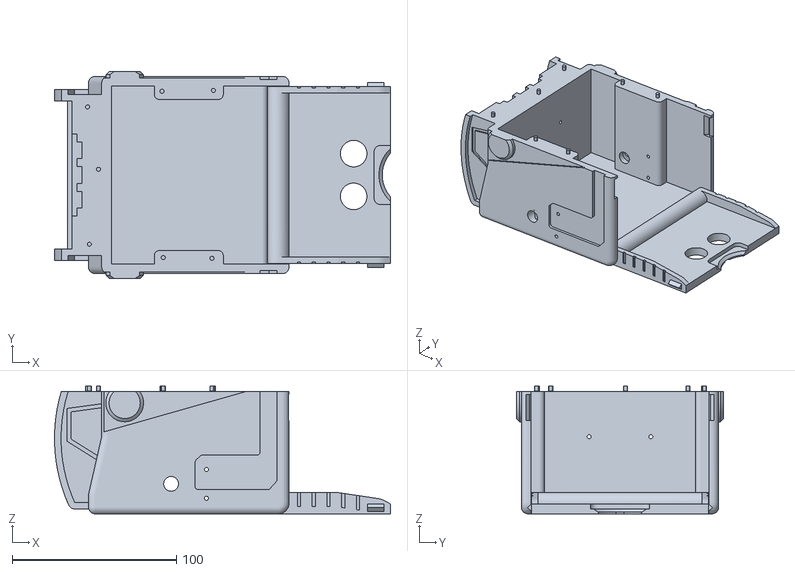
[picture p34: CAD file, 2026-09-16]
Modelo 3d/stl/corpo-wall-e-furado.stl
204.4 x 126.0 x 77.7

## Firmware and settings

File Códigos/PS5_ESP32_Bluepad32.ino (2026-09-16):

#include <Bluepad32.h>
#include <WiFi.h>
#include <ESPmDNS.h>
#include <ArduinoOTA.h>
#include <WebServer.h>
#include <Preferences.h>
#include "secrets.h"   // define WIFI_SSID e WIFI_PASS aqui (nao vai pro git)

const char* OTA_HOSTNAME = "carrinho-esp32";

// ---- Pinos dos motores ----
#define IN1 26   // Motor A
#define IN2 27
#define IN3 32   // Motor B (polaridade corrigida no codigo)
#define IN4 33

// Canais do PWM (core antigo do Bluepad32 usa API por canal, nao por pino)
#define CH_IN1 0
#define CH_IN2 1
#define CH_IN3 2
#define CH_IN4 3

// ---- Velocidade maxima (0 a 255) ----
int velMax = 200;

// ---- Suavidade da rampa ----
const int  RAMP_PASSO     = 12;
const long RAMP_INTERVALO = 15;

// Zona morta em unidades cruas do stick (eixo vai de -511 a 512)
const int ZONA_MORTA = 80;   // ~15% de 512

// Limiar dos gatilhos analogicos (throttle/brake vao de 0 a 1023)
const int LIMIAR_GATILHO = 400;

// ---- Sensor de distancia HC-SR04 (alimentado em 3.3V, sem divisor de tensao) ----
#define PINO_TRIG 4
#define PINO_ECHO 18

const int  DISTANCIA_MIN_CM    = 20;      // abaixo disso, bloqueia o avanco
const long SENSOR_INTERVALO    = 60;      // ms entre leituras
const unsigned long SENSOR_TIMEOUT_US = 15000UL; // ~2.5m, evita travar muito tempo sem eco

long distanciaCm = -1;   // -1 = sem leitura valida (fora de alcance ou nada na frente)
unsigned long ultimoSensor = 0;

// ---- Calibracao dos motores (0.30 a 1.00), ajustavel pela tela web ----
float trimA = 1.0f;
float trimB = 1.0f;

int alvoA = 0, alvoB = 0;
int atualA = 0, atualB = 0;
unsigned long ultimoRamp = 0;

ControllerPtr meuControle = nullptr;
Preferences prefs;
WebServer server(80);

int aproxima(int atual, int alvo) {
  if (atual < alvo) { atual += RAMP_PASSO; if (atual > alvo) atual = alvo; }
  else if (atual > alvo) { atual -= RAMP_PASSO; if (atual < alvo) atual = alvo; }
  return atual;
}

void aplicaMotorA(int s) {
  int sc = (int)(s * trimA);
  if (sc > 0) { ledcWrite(CH_IN1, sc);  ledcWrite(CH_IN2, 0); }
  else if (sc < 0) { ledcWrite(CH_IN1, 0); ledcWrite(CH_IN2, -sc); }
  else { ledcWrite(CH_IN1, 0); ledcWrite(CH_IN2, 0); }
}
void aplicaMotorB(int s) {           // polaridade invertida
  int sc = (int)(s * trimB);
  if (sc > 0) { ledcWrite(CH_IN3, 0); ledcWrite(CH_IN4, sc); }
  else if (sc < 0) { ledcWrite(CH_IN3, -sc); ledcWrite(CH_IN4, 0); }
  else { ledcWrite(CH_IN3, 0); ledcWrite(CH_IN4, 0); }
}

void atualizaRampa() {
  if (millis() - ultimoRamp < RAMP_INTERVALO) return;
  ultimoRamp = millis();
  atualA = aproxima(atualA, alvoA);
  atualB = aproxima(atualB, alvoB);
  aplicaMotorA(atualA);
  aplicaMotorB(atualB);
}

// Dispara o pulso, mede o eco e atualiza distanciaCm (em cm).
// So roda a cada SENSOR_INTERVALO ms pra nao travar o loop toda hora com o pulseIn.
void atualizaSensorDistancia() {
  if (millis() - ultimoSensor < SENSOR_INTERVALO) return;
  ultimoSensor = millis();

  digitalWrite(PINO_TRIG, LOW);
  delayMicroseconds(2);
  digitalWrite(PINO_TRIG, HIGH);
  delayMicroseconds(10);
  digitalWrite(PINO_TRIG, LOW);

  unsigned long duracao = pulseIn(PINO_ECHO, HIGH, SENSOR_TIMEOUT_US);
  if (duracao == 0) {
    distanciaCm = -1;  // sem eco: nada na frente dentro do alcance
  } else {
    distanciaCm = duracao / 58;  // formula padrao do HC-SR04
  }

  Serial.print("Distancia: ");
  if (distanciaCm < 0) Serial.println("sem leitura");
  else { Serial.print(distanciaCm); Serial.println(" cm"); }
}

// Chamado automaticamente quando um controle conecta
void onConnectedController(ControllerPtr ctl) {
  if (meuControle == nullptr) {
    Serial.println("Controle conectado!");
    meuControle = ctl;
  } else {
    Serial.println("Outro controle tentou conectar, ignorado (ja tem um em uso).");
  }
}

// Chamado automaticamente quando o controle desconecta
void onDisconnectedController(ControllerPtr ctl) {
  if (meuControle == ctl) {
    Serial.println("Controle desconectado.");
    meuControle = nullptr;
  }
}

// ---------------- Tela web de calibracao ----------------

const char PAGINA_HTML[] PROGMEM = R"rawliteral(
<!DOCTYPE html>
<html>
<head>
<meta charset="utf-8">
<meta name="viewport" content="width=device-width, initial-scale=1">
<title>Calibracao do carrinho</title>
<style>
  body { font-family: sans-serif; background:#111; color:#eee; text-align:center; padding:20px; }
  h1 { font-size: 1.3em; }
  .bloco { margin: 30px 0; }
  input[type=range] { width: 90%; height: 30px; }
  .valor { font-size: 1.5em; margin: 8px 0; }
  .aviso { font-size: 0.85em; color:#aaa; margin-top:30px; }
</style>
</head>
<body>
  <h1>Calibracao dos motores</h1>
  <p>Ande pra frente com o controle e ajuste o motor mais forte ate o carrinho andar reto.</p>

  <div class="bloco">
    <div>Motor A (esquerdo)</div>
    <div class="valor" id="valA">--</div>
    <input type="range" min="30" max="100" id="sliderA" oninput="mudou('a', this.value)">
  </div>

  <div class="bloco">
    <div>Motor B (direito)</div>
    <div class="valor" id="valB">--</div>
    <input type="range" min="30" max="100" id="sliderB" oninput="mudou('b', this.value)">
  </div>

  <div class="bloco">
    <div>Sensor de distancia (HC-SR04)</div>
    <div class="valor" id="valDist">--</div>
  </div>

  <p class="aviso">Os valores sao salvos automaticamente no ESP32.</p>

<script>
function carregar() {
  fetch('/get').then(r => r.json()).then(d => {
    document.getElementById('sliderA').value = Math.round(d.a * 100);
    document.getElementById('sliderB').value = Math.round(d.b * 100);
    document.getElementById('valA').innerText = Math.round(d.a * 100) + '%';
    document.getElementById('valB').innerText = Math.round(d.b * 100) + '%';
    document.getElementById('valDist').innerText = d.dist < 0 ? 'sem leitura' : d.dist + ' cm';
  });
}
setInterval(carregar, 500);
let tId = null;
function mudou(motor, val) {
  document.getElementById('val' + motor.toUpperCase()).innerText = val + '%';
  clearTimeout(tId);
  tId = setTimeout(() => enviar(), 150);
}
function enviar() {
  const a = document.getElementById('sliderA').value;
  const b = document.getElementById('sliderB').value;
  fetch('/set?a=' + a + '&b=' + b);
}
carregar();
</script>
</body>
</html>
)rawliteral";

void handleRoot() {
  server.send_P(200, "text/html", PAGINA_HTML);
}

void handleGet() {
  String json = "{\"a\":" + String(trimA, 2) + ",\"b\":" + String(trimB, 2) + ",\"dist\":" + String(distanciaCm) + "}";
  server.send(200, "application/json", json);
}

void handleSet() {
  if (server.hasArg("a")) {
    float v = server.arg("a").toFloat() / 100.0f;
    if (v < 0.30f) v = 0.30f;
    if (v > 1.00f) v = 1.00f;
    trimA = v;
    prefs.putFloat("trimA", trimA);
  }
  if (server.hasArg("b")) {
    float v = server.arg("b").toFloat() / 100.0f;
    if (v < 0.30f) v = 0.30f;
    if (v > 1.00f) v = 1.00f;
    trimB = v;
    prefs.putFloat("trimB", trimB);
  }
  server.send(200, "text/plain", "OK");
}

// ---------------- Setup / Loop ----------------

void setup() {
  Serial.begin(115200);
  ledcSetup(CH_IN1, 1000, 8);
  ledcAttachPin(IN1, CH_IN1);
  ledcSetup(CH_IN2, 1000, 8);
  ledcAttachPin(IN2, CH_IN2);
  ledcSetup(CH_IN3, 1000, 8);
  ledcAttachPin(IN3, CH_IN3);
  ledcSetup(CH_IN4, 1000, 8);
  ledcAttachPin(IN4, CH_IN4);

  pinMode(PINO_TRIG, OUTPUT);
  pinMode(PINO_ECHO, INPUT);
  digitalWrite(PINO_TRIG, LOW);

  // ---- Wifi ----
  WiFi.mode(WIFI_STA);
  WiFi.begin(WIFI_SSID, WIFI_PASS);
  Serial.print("Conectando no wifi");
  unsigned long inicio = millis();
  while (WiFi.status() != WL_CONNECTED && millis() - inicio < 15000) {
    delay(300);
    Serial.print(".");
  }
  if (WiFi.status() == WL_CONNECTED) {
    Serial.println();
    Serial.print("Wifi conectado! IP: ");
    Serial.println(WiFi.localIP());

    // ---- OTA ----
    if (MDNS.begin(OTA_HOSTNAME)) {
      Serial.println("mDNS ok");
    }
    ArduinoOTA.setHostname(OTA_HOSTNAME);
    ArduinoOTA.begin();
    Serial.println("OTA pronto. No Arduino IDE: Tools > Port > deve aparecer 'carrinho-esp32' na rede.");

    // ---- Tela de calibracao ----
    prefs.begin("carrinho", false);
    trimA = prefs.getFloat("trimA", 1.0f);
    trimB = prefs.getFloat("trimB", 1.0f);
    server.on("/", handleRoot);
    server.on("/get", handleGet);
    server.on("/set", handleSet);
    server.begin();
    Serial.print("Calibracao: abra http://");
    Serial.print(WiFi.localIP());
    Serial.println(" no navegador do celular (mesmo wifi).");
  } else {
    Serial.println();
    Serial.println("Nao conectou no wifi. Seguindo sem OTA/calibracao web.");
  }

  Serial.println("Inicializando Bluepad32...");
  BP32.setup(&onConnectedController, &onDisconnectedController);

  // So descomente a linha abaixo, grave, teste, e comente de novo depois.
  // Ela apaga pareamentos antigos guardados no ESP32 -- util se o
  // controle ficar "preso" tentando reconectar em algo que nao existe mais.
  // BP32.forgetBluetoothKeys();

  Serial.println("Pronto. Coloque o controle em modo pareamento (PS + Create ate piscar rapido).");
}

void loop() {
  ArduinoOTA.handle();
  server.handleClient();

  atualizaRampa();
  atualizaSensorDistancia();  // roda mesmo sem controle conectado, bom pra testar so com o Serial Monitor

  // Busca dados novos do controle (precisa ser chamado sempre no loop)
  BP32.update();

  if (meuControle == nullptr || !meuControle->isConnected() || !meuControle->isGamepad()) {
    alvoA = 0; alvoB = 0;
    return;
  }

  // Leitura crua dos eixos (-511 a 512).
  // axisY: empurrar pra CIMA da valor NEGATIVO, entao invertemos o sinal.
  int frente = -meuControle->axisY();   // stick esquerdo, eixo Y
  int giro   =  meuControle->axisRX();  // stick direito, eixo X

  if (abs(frente) < ZONA_MORTA) frente = 0;
  if (abs(giro)   < ZONA_MORTA) giro   = 0;

  int fr = map(frente, -511, 512, -velMax, velMax);
  int gr = map(giro,   -511, 512, -velMax, velMax);

  // Freio de seguranca: se tem objeto perto, bloqueia so o avanco (re e giro continuam liberados)
  bool objetoPerto = (distanciaCm >= 0 && distanciaCm < DISTANCIA_MIN_CM);
  if (objetoPerto && fr > 0) fr = 0;

  int a = fr + gr;   // motor A
  int b = fr - gr;   // motor B
  a = constrain(a, -velMax, velMax);
  b = constrain(b, -velMax, velMax);

  alvoA = a;
  alvoB = b;

  // Gatilhos analogicos: throttle() = R2, brake() = L2 (0 a 1023)
  if (meuControle->throttle() > LIMIAR_GATILHO) { velMax += 1; if (velMax > 255) velMax = 255; }
  if (meuControle->brake()    > LIMIAR_GATILHO) { velMax -= 1; if (velMax < 80)  velMax = 80; }

  delay(15);
}

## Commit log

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2026-08-26 Aula 17 | MVP
    [Planilha-de-custos.xlsx]
2026-08-26 Aula 17 | MVP - Passando MD para HTML
    [Planilha-de-custos.xlsx]
2026-09-16 CP1 | Versao final: firmware ESP32, modelo 3D e documentacao alinhada
    Firmware oficial (ESP32 + PS5 DualSense via Bluepad32) versionado e
    documentacao reescrita para descrever o robo entregue, nao mais a
    concepcao inicial.
    Codigo:
    - Adiciona Codigos/PS5_ESP32_Bluepad32.ino, README e secrets.h.example
    - Move os sketches de bancada para Codigos/testes-aula16/ e corrige os
    links quebrados que apontavam para a raiz
    - Cria .gitignore protegendo secrets.h
    Modelo 3D:
    - Exporta STL das pecas desenvolvidas pela equipe (corpo furado,
    extensor de eixo, roda boba e travessa interna)
    - Extrai os 16 renders das chapas de impressao do projeto do slicer
    - Documenta adaptacoes, corte do corpo, parametr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
    [Wall-E_Articulated(3).3mf, corpo-wall-e-furado.stl, extensor-de-eixo.stl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]
2026-09-16 CP1 | Evidencias finais e correcao da tracao real do robo
    Fotos e videos do robo finalizado organizados, e documentacao corrigida
    para descrever a tracao que o robo realmente usa.
    Midias:
    - 6 fotos renomeadas e movidas para imagens/robo-final/ (4 vistas do
    robo montado, 1 com o compartimento frontal aberto)
    - 4 videos da demonstracao final movidos para video/
    Correcao de tracao:
    - O robo anda com 2 rodas de borracha acopladas aos eixos dos motores
    pelo extensor impresso, e nao com as esteiras em TPU do modelo
    original. Os conjuntos laterais impressos servem de apoio no piso e
    de elemento visual
    - Corrige README, Documentacao.md e Modelo 3d/README.md, incluindo
    ficha de requisitos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
2026-09-16 CP1 | Renomeia videos do funcionamento e liga no README e na secao 28
    Os quatro videos finais registram o funcionamento geral do robo, todos
    com o controle PS5 em uso. Renomeados para funcionamento-1..4.mp4 e
    referenciados no README e na secao 28.3, com apontamento para o video
    de bancada que demonstra o sensor de aproximacao.
2026-09-17 CP1 | Adiciona diagrama de conexoes do ESP32 (secao 24.3)
    Faltava o esquema de ligacoes da versao final -- os diagramas existentes
    eram todos da montagem de bancada com Arduino. Adiciona diagrama Mermaid
    e tabela de ligacoes ponto a ponto entre ESP32, ponte H, motores, sensor
    e bateria, com as ressalvas dos jumpers ENA/ENB e do terra comum.
    Renumera as subsecoes seguintes da secao 24 e corrige as referencias
    cruzadas afetadas.
2026-09-17 CP1 | Corrige alimentacao para 6 pilhas AA
    A montagem final usa 6 pilhas AA (9 V nominais), e nao 4 como constava
    no planejamento. Corrige README, ficha de requisitos, especificacoes,
    lista de componentes, diagrama de arquitetura, distribuicao interna e
    secao de alimentacao, com a justificativa da escolha (queda de ~2 V do
    L298N entre entrada e saida de potencia).
2026-10-13 CP2 | Firmware e script de coleta do HC-SR04 para o dataset
    Inicio do CP2 (TinyML). O firmware de coleta le o HC-SR04 do carrinho nos
    mesmos pinos do CP1, em ritmo fixo de 60 ms, e envia timestamp,distancia
    pela serial. Leituras sem eco ou acima de 200 cm viram 200 cm -- o mesmo
    tratamento que o firmware com o modelo embarcado vai usar.
    O script coletar.py grava amostras de 3 s (50 leituras) em CSV rotulado
    (dataset/<classe>.<NNN>.csv), no formato que o Edge Impulse importa e
    rotula pelo nome do arquivo. Classes: vazio, parado, aproximando, aceno.
2026-10-13 CP2 | Firmware com inferencia TinyML embarcada e acoes no carrinho
    Evolucao do firmware do CP1 (que continua intacto em Codigos/). O HC-SR04
    passa a ser lido no ritmo do dataset (EI_CLASSIFIER_INTERVAL_MS, 60 ms)
    numa janela deslizante de 30 leituras, e o modelo do Edge Impulse roda a
    cada 300 ms no ESP32.
    A classe confirmada (confianca >= 0,80 em duas inferencias seguidas)
    muda o comportamento:
    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
2026-10-13 CP2 | README da pasta CP2-TinyML: modelo, coleta, Edge Impulse e gravacao
    Descreve as classes e as acoes no carrinho, a organizacao da pasta, o
    passo a passo para reproduzir (coleta, impulse, deploy e gravacao) e a
    comparacao CP1 -> CP2. Registra os cuidados descobertos na compilacao:
    98% da particao padrao, warnings em Default e limite de caminho do
    Windows.
2026-10-13 CP2 | Dataset simulado do HC-SR04: gerador e 200 amostras
    O dataset do CP2 e SIMULADO: gerado por simulacao/gerar_dataset.py
    (semente 2026, reproduzivel), e nao medido com o sensor. O formato e o
    mesmo do firmware de coleta -- timestamp,distancia a cada 60 ms, 50
    leituras por amostra, sem eco gravado como 200 cm -- entao uma coleta
    real pode substituir os arquivos sem outra mudanca.
    O modelo do sensor inclui ruido proporcional a distancia, falhas de eco
    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
2026-10-14 CP2 | Edge Impulse: treino, teste e biblioteca Arduino exportada
    Projeto carrinho_walle_tinyml, treinado com o dataset simulado:
    - 168 amostras unicas aceitas (32 de "vazio" eram copias exatas e foram
    recusadas pelo Edge Impulse), 136 de treino e 32 de teste
    - impulse: janela 1800 ms, passo 300 ms, 16,67 Hz -> Raw Data (escala
    0,01) -> rede densa 20/10, 100 ciclos, taxa 0,005; alvo ESP32 240 MHz
    - validacao: 91,2% (int8 igual ao float32)
    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
2026-10-14 CP2 | Documentacao do CP2: dataset, Edge Impulse, integracao e testes
    Novas secoes 29 a 33 na Documentacao.md:
    - 29: objetivo, por que um modelo, classes e acoes, onde esta cada parte
    - 30: dataset -- declarado como SIMULADO, como foi gerado, quantidades
    (200 gerados, 168 unicos aceitos, 136/32, 680 janelas)
    - 31: Edge Impulse -- divisao, impulse, Raw Data, modelo, validacao
    91,2%, teste 85,0% com matrizes de confusao, deploy e prints
    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
2026-10-14 CP2 | Dataset v2: simulacao recalibrada com o primeiro teste no carrinho
    O primeiro teste com o modelo v1 gravado no carrinho (log em
    evidencias/inferencias-testes-no-carrinho.csv, capturado pela rede com o
    novo ferramentas/monitorar.py) mostrou:
    - aceno confundido com aproximacao: a mao entrando no feixe (200 -> ~60
    cm) parecia a aproximacao simulada, que tinha falhas de eco demais
    - aproximacao lenta (~4,5 cm/s) classificada como "parado": a v1 so
    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
2026-10-14 CP2 | Edge Impulse v2: Raw Data + Flatten, treino, teste e biblioteca
    Novo projeto carrinho_walle_tinyml_v2 (o v1 fica intacto como historico)
    com o dataset simulado v2: 262 amostras unicas (210 treino / 52 teste).
    Com o impulse do v1 (so Raw Data, rede 20/10) a validacao caiu para
    78,1%: aproximacoes lentas sao dificeis de separar de "parado" olhando
    so as 30 leituras. Acrescentado um bloco Flatten (media, min, max, RMS,
    desvio, assimetria, curtose) ao lado do Raw Data -- 37 features -- e
    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
2026-10-14 CP2 | Log do teste do modelo v2 no carrinho
    Log de 20 min (3066 inferencias) capturado pela rede com
    ferramentas/monitorar.py enquanto o firmware v2 rodava no carrinho.
    Mostra aceno e aproximacao disparando as manobras, mas tambem as
    confusoes que motivaram a v3: aproximacao lenta classificada como
    "parado" e trocas entre classes com fronteiras proximas.
2026-10-14 CP2 | Dataset v3: duas classes (seguro / inseguro) pela velocidade de aproximacao
    Quatro classes com fronteiras proximas continuaram se confundindo no
    carrinho (parado x aproximacao lenta, aceno x aproximacao). O grupo
    simplificou a pergunta do modelo: a distancia esta diminuindo rapido
    demais?
    - seguro: obstaculo parado, aproximacao lenta (1,5 a 12 cm/s), re,
    giro e mao passando
    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
2026-10-14 CP2 | Firmware v3: diagnostico de reinicio e Wi-Fi com menos potencia
    - motivo do ultimo reinicio (esp_reset_reason: brownout, panic,
    watchdog...) e tempo ligado no Serial, no painel web e em /get;
    monitorar.py grava o motivo em cada linha
    - Wi-Fi com potencia de transmissao de 11 dBm: picos de corrente
    menores, porque Wi-Fi + Bluetooth + motores no chao derrubavam o ESP32
    Compila: 1.292.353 bytes (98%).
2026-10-14 CP2 | Firmware v3: arranque mais suave contra brownout
    O diagnostico confirmou: os reinicios no chao sao brownout (a tensao
    das pilhas cai quando os motores fazem forca). Para reduzir o pico de
    corrente:
    - rampa de 12 para 6 unidades a cada 15 ms (0 -> 170 em ~0,5 s); o
    freio do modelo continua instantaneo
    - velocidade maxima inicial de 200 para 170 (R2 ainda sobe ate 255)
    Paliativo: a correcao definitiva e pilhas novas ou alimentacao
    separada para o ESP32.
2026-10-14 CP2 | Log do segundo teste da v3: brownout confirmado e freio com pilhas novas
    16:38 a 18:18, uma linha por leitura, com o motivo do ultimo reinicio.
    - com as pilhas do dia: 3 reinicios, todos "brownout"; o arranque mais
    suave reduziu, mas nao eliminou
    - com pilhas novas (18:13-18:18): nenhum reinicio; 7 freadas com
    aproximacao de 21-32 cm/s e inseguro 82-96%, cinco delas a 34-42 cm,
    logo ao entrar na zona de 50 cm; aproximacoes de 6-9 cm/s sem freio
2026-10-14 CP2 | Documentacao: resultados da v3 no carrinho e brownout
    - 32.6 (nova): controle desconectando -> ESP32 reiniciando ->
    diagnostico pelo motivo do reinicio -> brownout das pilhas; mudancas
    no firmware (Wi-Fi 11 dBm, rampa mais suave, velocidade inicial 170)
    e solucao (pilhas novas; ESP32 com alimentacao separada para 21/10)
    - 33.1/33.2: resultados reais T21-T26 da v3
    - 33.3: fronteira de ~20 cm/s confirmada no carrinho; limitacao das
    pilhas AA
    - READMEs com o resultado no carrinho e checklist atualizado
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
